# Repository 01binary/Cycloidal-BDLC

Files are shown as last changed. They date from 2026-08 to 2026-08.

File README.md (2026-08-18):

# Internal-Cycloidal-Actuator

A Quasi Direct Drive (QDD) robotics servo-motor with 8:1 cycloidal drive.

> Forked from [Internal-Cycloidal-Actuator](https://github.com/aaedmusa/Internal-Cycloidal-Actuator) by Aaed Musa.

|||
|-|-|
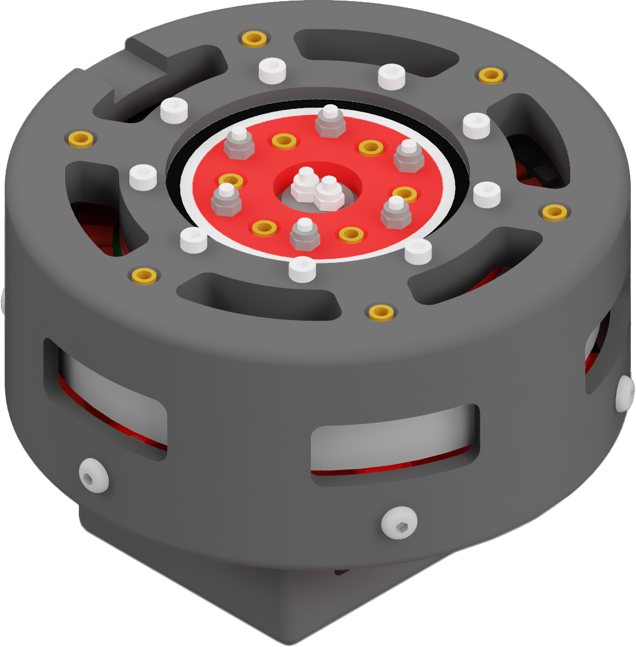
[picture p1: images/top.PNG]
top
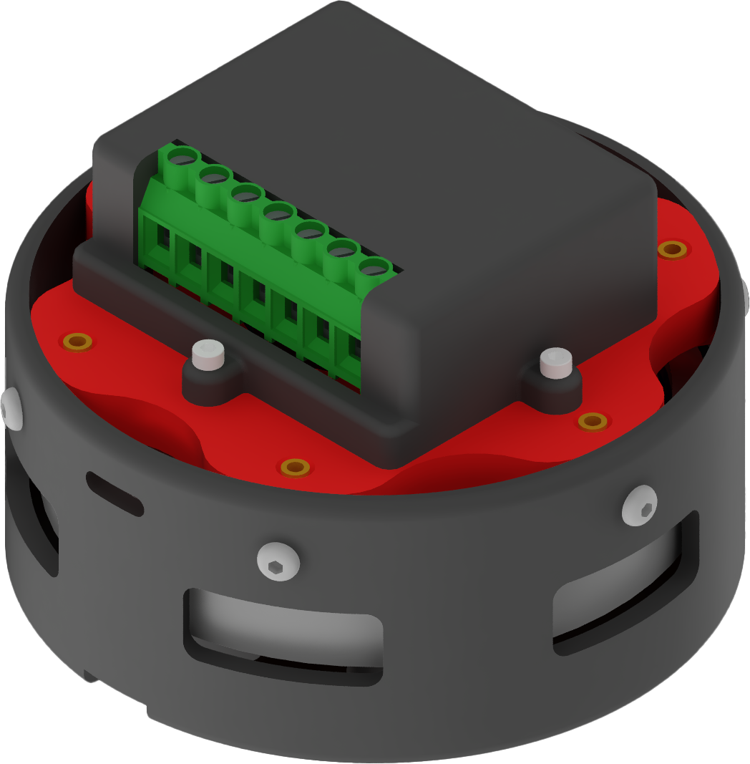
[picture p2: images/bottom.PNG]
bottom
||

The BDLC motor is built on [10010 stator](https://www.aliexpress.us/item/3256805244129270.html) made from laminated steel sheets which increases the flux while preventing [eddy current loss](https://en.wikipedia.org/wiki/Eddy_current).

The stator has `36` slots, wound with `6` strands of `26 AWG` copper wire at `6` turns per slot (effectively `36` total turns per slot).

The rotor is machined out of 1045 Mild Steel to increase the flux of the `42`x`N52` permanent magnets attached to the rotor with JB Weld.

The actuator uses an `8:1` [cycloidal gear drive](https://en.wikipedia.org/wiki/Cycloidal_drive) mounted at the center of the motor.

The fixed ring of the gearbox (composed of roller pins) is machined out of Aluminum 6061 and fits into the center of the stator with Loctite 648 retaining compound.

The eccentric shaft of the gearbox directly mounts to the rotor of the motor. The gearbox is essentially part of the motor.

The actuator uses an [ODrive S1](https://odriverobotics.com/shop/odrive-s1) FOC Controller giving it the ability to lift loads and move to exact positions.

## Specifications

+ `36N42P` Configuration
+ `125mm` Diameter x `84mm` Height
+ `1023g` Mass
+ `209RPM` Speed at `22.2V`
+ `16.17Nm` Torque
+ `75 mOhm` Phase Resistance
+ `41.05 uH` Phase Inductance

## Bill of Materials

|Image|Component|Qty|
|-|-|-|
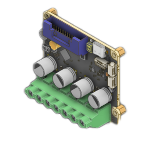
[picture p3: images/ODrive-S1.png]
ODrive S1
||[ODrive S1 (w/Screw Terminals)](https://odriverobotics.com/shop/odrive-s1)|1
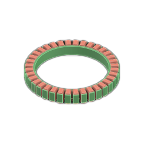
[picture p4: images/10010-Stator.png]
Stator
||[10010 Stator](https://www.aliexpress.us/item/3256805244129270.html)|1
||[26 AWG Magnet Wire](https://www.amazon.com/dp/B0978CM2NP)|1
||[10x5x3mm N52 Magnets](https://jc-magnetics.com/Magnet-N50-10mm-5mm-3mm-Block)|42
||[⌀8 x 2.5mm Encoder Magnet](https://www.andymark.com/products/redline-encoder-magnet)|1
||[3x10x4mm Bearings](https://www.amazon.com/dp/B07FW389P1?psc=1&ref=ppx_yo2ov_dt_b_product_details)|12
||[12x21x5mm Bearings](https://www.amazon.com/dp/B07FVYHWFC?psc=1&ref=ppx_yo2ov_dt_b_product_details)|4
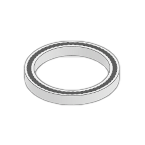
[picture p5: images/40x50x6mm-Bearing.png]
40x50x6 Bearing
||[40x50x6mm Bearing](https://www.amazon.com/XIKE-6708-2RS-Bearings-40x50x6mm-Pre-Lubricated/dp/B09D2RCCBG)|1
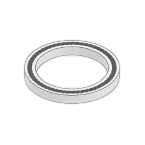
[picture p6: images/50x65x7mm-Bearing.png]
50x65x7 Bearing
||[50x65x7mm Bearing](https://www.amazon.com/6810-2RS-Bearings-50x65x7mm-Pre-Lubricated-Bearing/dp/B09D2XDT95)|1
||[M3 x 6mm Inserts](https://www.amazon.com/gp/product/B07LBQRYR3)|22
||[M3 x 5mm Hex Standoffs](https://www.amazon.com/DTGN-M3x5mm-DXL-Standoff-Electronic/dp/B0BC8X9CPK)|18
||[M3 Locknuts](https://www.amazon.com/100Pcs-Stainless-Self-Lock-Inserted-Clinching/dp/B075ZZW7VL)|17
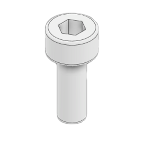
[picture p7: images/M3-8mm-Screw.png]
M3x8
||[M3 x 8mm Screws](https://www.amazon.com/gp/product/B08GLLBCYV)|4
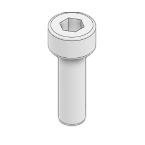
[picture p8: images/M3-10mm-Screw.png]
M3x10
||[M3 x 10mm Screws](https://www.amazon.com/Fullerkreg-Socket-Stainless-Machine-Quantity/dp/B07CK3RSN3)|4
||[M3 x 35mm Screws](https://www.amazon.com/DTGN-M3x40mm-Stainless-Machine-Threaded/dp/B0CFV5BLRP)|9
||[M3 x 40mm Screws](https://www.amazon.com/DTGN-M3x40mm-Stainless-Machine-Threaded/dp/B0CFV44M5J)|6
||[M3 x 50mm Screws](https://www.amazon.com/uxcell-M3x50mm-0-5mm-Socket-Screws/dp/B011BNTHPS)|2
||[M4 Locknuts](https://www.amazon.com/gp/product/B08LMNFS5P)|14
||[M4 x 14mm Screws](https://www.amazon.com/M4x12mm-M4-0-7x12mm-Stainless-Machine-Quantity/dp/B0CLGWZSLT)|14
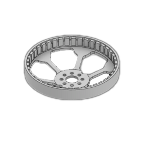
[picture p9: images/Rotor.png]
Rotor
||Machined Rotor (Mild Steel 1045)|1
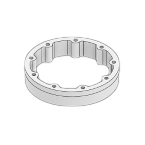
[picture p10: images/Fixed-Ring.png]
Fixed Ring
||Machined Fixed Ring (Aluminum 6061)|1
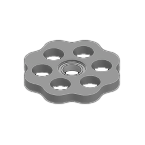
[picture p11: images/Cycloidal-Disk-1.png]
Cycloidal Disk 1
||Cycloidal Disk 1 (Mild Steel 1045)|1
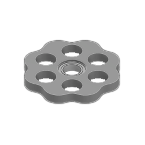
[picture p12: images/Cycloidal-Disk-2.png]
Cycloidal Disk 2
||Cycloidal Disk 2 (Mild Steel 1045)|1
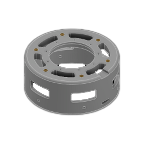
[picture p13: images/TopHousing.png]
Top Housing
||Top Housing (Aluminum 6061)|1
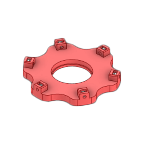
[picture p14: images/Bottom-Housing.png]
Bottom Housing
||Bottom Housing (Aluminum 6061)|1
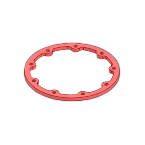
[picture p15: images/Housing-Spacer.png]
Housing Spacer
||Housing Spacer|1
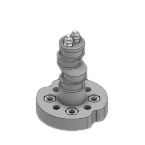
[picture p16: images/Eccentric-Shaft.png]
Eccentric Shaft
||Eccentric Shaft|1
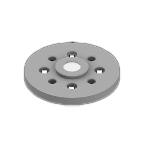
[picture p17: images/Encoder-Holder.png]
Encoder Flange
||Encoder Flange|1
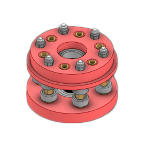
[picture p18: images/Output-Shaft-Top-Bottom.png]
Output Shaft
||Output Shaft Top/Bottom|1

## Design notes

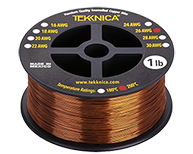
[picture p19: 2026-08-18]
images/Magnet-Wire.png

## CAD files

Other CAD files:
parts/10010 Stator.ipt
parts/12x21x5mm Bearing.ipt
parts/3x10x4mm Bearing.ipt
parts/40x50x6mm_Bearing.ipt
parts/50x65x7mm_Bearing.ipt
parts/8x2mm Magnet.ipt
parts/Bottom Shaft.ipt
parts/Bottom_Housing.ipt
parts/Cycloidal_Disk_1.ipt
parts/Cycloidal_Disk_2.ipt
parts/Eccentric Shaft.ipt
parts/Encoder_Holder.ipt
parts/Fixed_Ring.ipt
parts/Housing_Spacer.ipt
parts/Internal Cycloidal Actuator.iam
parts/M3_10mm_Screw.ipt
parts/M3_35mm_Screw.ipt
parts/M3_8mm_Screw.ipt
parts/M3_Locknut.ipt
parts/M3x40mm Screw.ipt
parts/M3x5 Standoff.ipt
parts/M3x50 Screw.ipt
parts/M3x6mm Insert.ipt
parts/M4 Locknut.ipt
parts/M4_12mm_Screw.ipt
parts/ODrive_S1_Cover.ipt
parts/OldVersions/Cycloidal_Disk_1.0001.ipt
parts/OldVersions/Cycloidal_Disk_2.0001.ipt
parts/OldVersions/Encoder_Holder.0001.ipt
parts/OldVersions/Internal Cycloidal Actuator.0002.iam
parts/OldVersions/Output Shaft.0001.iam
parts/Output Shaft.iam
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

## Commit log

2025-12-29 Clean up repo
    [10010 Stator.ipt, 40x50x6mm_Bearing.ipt, 50x65x7mm_Bearing.ipt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]
2025-12-29 Re-org and add thumbnails
    [10010 Stator.ipt, 40x50x6mm_Bearing.ipt, 50x65x7mm_Bearing.ipt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]
2026-08-18 Separate bottom housing assembly into parts
    [Bottom_Housing.ipt, M3x6mm Insert.ipt]
2026-08-18 Separate all parts
    [12x21x5mm Bearing.ipt, 3x10x4mm Bearing.ipt, 8x2mm Magnet.ipt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]
